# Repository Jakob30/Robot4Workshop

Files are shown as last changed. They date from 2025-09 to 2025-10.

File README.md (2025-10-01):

# Roboterarm – Aufbau und Inbetriebnahme

<p align="center">
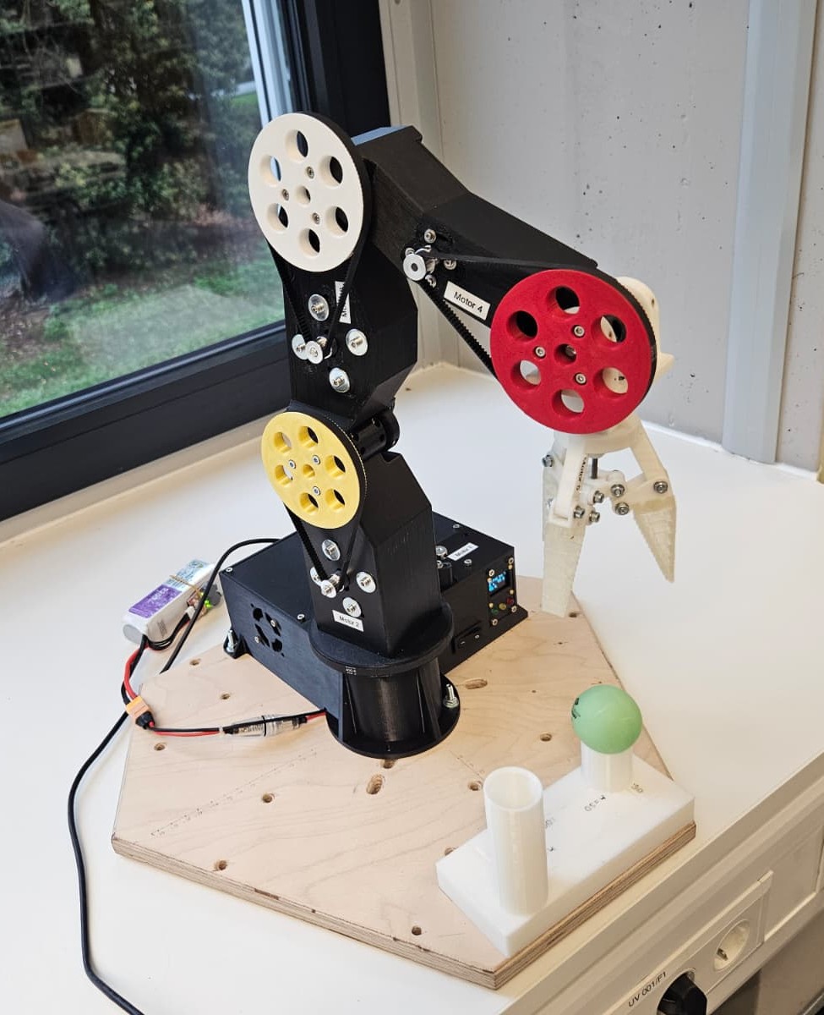
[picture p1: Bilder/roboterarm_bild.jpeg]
Roboterarm
    
</p>    

Dieses Projekt beschreibt den Aufbau und die Inbetriebnahme eines Roboterarms, der mithilfe von 3D-gedruckten Teilen, einer selbstgefertigten Platine und einem STM32F4-Mikrocontroller gesteuert wird.  

---

## 📦 Vorbereitung

1. **3D-Druckteile**  
   - Alle benötigten Teile laut STL-Dateien ausdrucken. Detaillierte Anweisungen befinden sich in dieser [README im Roboterarm Ordner](./Roboterarm/README.md).
   - Qualität und Stabilität der Teile prüfen.  

2. **Bestellung von Bauteilen**  
   - Alle mechanischen und elektronischen Komponenten von der Bestellliste besorgen.  

---

## 🔧 Zusammenbau

Wenn alle 3D-Druckteile und Bauteile vorhanden sind, den Arm gemäß der [**Montageanleitung**](./Roboterarm/Montagehinweise.pdf) zusammenbauen.   

---

## 🖥️ Platine (PCB)

1. **Fertigung**  
   - Platinendaten herunterladen und bei einem Hersteller fertigen lassen. Hinweise zur Platinenfertigung findet man im [Elektronik Ordner](./Elektronik/README.md).

2. **Bestückung**  
   - Bauteile wie Headerpins und Widerstände auf die Platine löten (siehe [README im Elektronik Ordner](./Elektronik/README.md)).  
   - Anschließend können Treiber, Nucleoboard und OLED aufgesteckt werden.

3. **Stromversorgung**  
   - Ein zusätzliches Kabel löten, das den Akku mit der Sicherung, dem Schalter und anschließend mit dem DC/DC-Wandler verbindet.  

---

## ⚙️ STM32F4 – Software

1. **Setup**  
   - [STM32CubeIDE](https://www.st.com/en/development-tools/stm32cubeide.html) installieren.  
   - Projektdateien aus [STM32F4 Ordner](./STM32F4/) importieren.
  
2. **Stromversorgung**  
   - Platine mit Akku oder Netzgerät mit Versorgungsspannung von ca. 15V verbinden.  
   - Schalter umlegen. 
  
3. **Anpassung** 
   - Bewegungen werden im `main.c` programmiert und alle aufzurufenden Funktionen sind in [README](./STM32F4/README.md) beschrieben.  
   - Code per USB auf den Mikrocontroller hochladen.  

---

## 🔍 Kalibrierung mit StallGuard

Vor der ersten Inbetriebnahme ist eine Kalibrierung der StallGuard-Werte notwendig.  
Empfohlen wird die Nutzung von **STM32CubeMonitor**, um Variablen in Echtzeit auszulesen.  

Wichtige Parameter:  
- `STALL_BUFFER_M_X`  
- `LOW_COUNTER_THRESHOLD_M_X`  
- `STALL_MAX_M_X`  

---

## ▶️ Start

1. Vor dem Start den **schwarzen Reset-Knopf** am Nucleo-Board drücken.  
2. Mit dem **blauen Userbutton** das Programm starten.  

---

## 🎥 Beispielvideo

Einen Eindruck, wie der fertige Roboterarm aussehen kann, gibt es hier:  
[➡️ Video ansehen](https://www.dropbox.com/scl/fi/g09jmz12r2tmc5cvw9wto/Robot4Workshop_v4.mp4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)

---

## ✅ Hinweis

- Alle Arbeitsschritte sorgfältig durchführen.  
- Sicherheitsaspekte beim Umgang mit Stromversorgung und Lötarbeiten beachten.

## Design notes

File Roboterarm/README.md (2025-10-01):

# 3D Modelle Roboterarm

Die M3-Einschmelzmuttern sind rot eingefärbt. Verschraubungen vollständig im Modell.

## Creo8 Modell
Alle 3D-Modelle der einzelnen Teile befinden sich im Ordner **`Creo8 Modelle`**.  
Die Baugruppenstruktur ist folgendermaßen verschachtelt:
```
roboterarm_gesamt.asm
│
├─ basis.asm
│ └─ riemenspanner.asm
├─ element1.asm
├─ element2.asm
├─ element3.asm
└─ greifer.asm
  └─ greiferfingereinheit.asm
```

> Hinweis: Alle Dateien liegen unsortiert in einem Ordner.  
> Dadurch kann dieser Ordner direkt als Arbeitsverzeichnis genutzt werden.  
> Die Überbaugruppe **`roboterarm_gesamt.asm`** ruft alle weiteren Dateien automatisch auf.

Die Gesamtbaugruppe ist flexibel und kann per *„Komponente ziehen“* bewegt werden.  
Auch die Greiferbaugruppe ist beweglich.

---

## STEP Modell
Für eine schnelle Ansicht der Gesamtbaugruppe oder für Nutzer ohne Creo8-Zugang kann die Datei  
**`roboterarm_gesamt_asm.stp`** in beliebiger CAD-Software importiert werden.

---

## 3D Druck
Die **`.stl`-Dateien** der 3D-Druckteile befinden sich im Ordner **`STL Dateien`**.  

- Für die **Zahnscheiben** wird höchstens eine **0.4 mm Düse** empfohlen.  
- Die **bionischen Finger** müssen mit flexiblem Filament (z. B. **TPU**) gedruckt werden.

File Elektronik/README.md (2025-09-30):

# Elektronik – PCB_Layout (KiCad)

Diese README beschreibt **alles rund um die Leiterplatte**: warum KiCad, was im Ordner `PCB_Layout/` liegt, wie du die Platine **fertigen lässt**, **Bauteile bestellst**, **bestückst** und **in Betrieb nimmst**.

---

## Warum KiCad?

* **Open‑Source & kostenlos**: Reproduzierbar für alle – ideal für ein Open‑Hardware‑Projekt.
* **Versionierbar**: Textbasierte Projektdateien → gut in Git nutzbar.
* **Ökosystem**: iBOM, DRC/ERC‑Checks, Plugin‑Support.

> Getestet mit **KiCad 8.x**. Ältere Versionen funktionieren u. U. nicht.

---

## Ordnerstruktur

```
Elektronik/
└─ PCB_Layout/
   ├─ PCB_Layout.kicad_pro           # Projektdatei (KiCad 8)
   ├─ PCB_Layout.kicad_sch           # Top‑Schaltplan (inkl. Hierarchie)
   ├─ PCB_Layout.kicad_pcb           # Leiterplattenlayout
   ├─ power.kicad_sch                # Sheet: Versorgung/15 V → 5 V 
   ├─ nucleo_F446RE.kicad_sch        # Sheet: NUCLEO‑F446RE 
   ├─ motor_driver.kicad_sch         # Sheet: TMC2209‑Treiber & Motoranschlüsse
   ├─ display_und_LED.kicad_sch      # Sheet: OLED, LEDs
   ├─ AOM12864A0-1.54WW-ANO/         # **Custom Footprint/Symbol** (OLED 1.54")
   ├─ DM-OLED096-636/                # **Custom Footprint/Symbol** (OLED 0.96")
   ├─ NUCLEO-F446RE/                 # **Custom Footprint/Symbol** (Nucleo STM32)
   ├─ TMC2209_SILENTSTEPSTICK/       # **Custom Footprint/Symbol** (Treiber‑Modul)
   ├─ PCB_Layout----
```

**Hinweis zu den Unterordnern:** `AOM12864…`, `DM‑OLED096‑636`, `NUCLEO‑F446RE`, `TMC2209_SILENTSTEPSTICK` enthalten die **projektspezifischen Bibliotheken** (Symbole/Footprints), die **nicht in KiCads Standard‑Libs** vorhanden sind. Damit bleibt das Projekt **voll reproduzierbar**.

---

## Platinenfertigung – Schritt für Schritt

### 1) Gerber/Bohrdaten erzeugen (KiCad)

1. Projekt öffnen → PCB-Editor.
2. **Datei → Plot**

   * Format: **Gerber**
   * Lagen (typisch 2‑lagig): `F.Cu`, `B.Cu`, `F.SilkS`, `B.SilkS`, `F.Mask`, `B.Mask`, `Edge.Cuts` (ggf. `F.Paste/B.Paste` bei Reflow‑SMD)
   * Allgemeine Optionen → Abwählen **Footprintwerte plotten**
   * **Plotten** → anschl. **Bohrdateien generieren**.

3. **ZIP‑Archiv** aus allen Gerber + Drill → `fabrication/<projekt>_gerbers.zip`.

### 2) Hersteller auswählen & bestellen

Wir haben u. a. bei **Multi‑CB** (Multi Circuit Boards) gefertigt: [https://portal.multi-circuit-boards.eu/](https://portal.multi-circuit-boards.eu/)

**Vorgehen (Beispiel Multi‑CB):**

1. Portal öffnen → Online‑Kalkulator → **Optional: CAD-Datei automatisch auslesen** klicken → **Datei anhängen** und dann `fabrication/<projekt>_gerbers.zip` hochladen.
2. Stückzahl auswählen (z. B. 5–10 Stück) & Lieferzeit.
4. Bestellung abschließen.

> Andere Fertiger funktionieren ebenso, solange sie Standard‑Gerber akzeptieren.

---

## Stückliste (BOM) & Bauteilbestellung

### 1) BOM in KiCad erzeugen

* **Schaltplan‑Editor → Werkzeuge → Stückliste (BoM) erstellen** 
* **Exportieren** als CSV → `outputs/bom.csv`.

### 2) Teile kaufen

* Öffne `bom.csv` → bestelle nach **MPN** (Manufacturer Part Number) bei Distributor deiner Wahl (z. B. Conrad, Mouser, etc.).
* Die restlichen Module (z. B. **TMC2209 Treiber**, **NUCLEO‑F446RE**, **OLED 0.96"**) findest du in [dieser Bestellliste](../Bestellliste.xlsx)

> Tipp: SMD Widerstände/Kondensatoren sind i. d. R. 1206 Hand‑Solder‑freundlich.

---

## Bestückung & Montage

### Reihenfolge (empfohlen)

1. **SMD zuerst**, klein → groß (falls SMD vorhanden). Reflow oder Handlötung.
2. **THT** (Stiftleisten, Buchsenleisten, Schraubklemmen).

>Hinweis: Unten auf dem PCB sieht man, dass die Treiber, MCU und OLED Display direkt auf dem PCB gelötet werden können. Allerdings empfehlen wir, die Buchsenleisten an diesen Stellen zu löten und dann Treiber, MCU, Display darauf zu stecken. Damit lassen sich diese Bauteile problemlos ein-/ausstecken, ohne entlöten zu müssen. 

<p align="center">
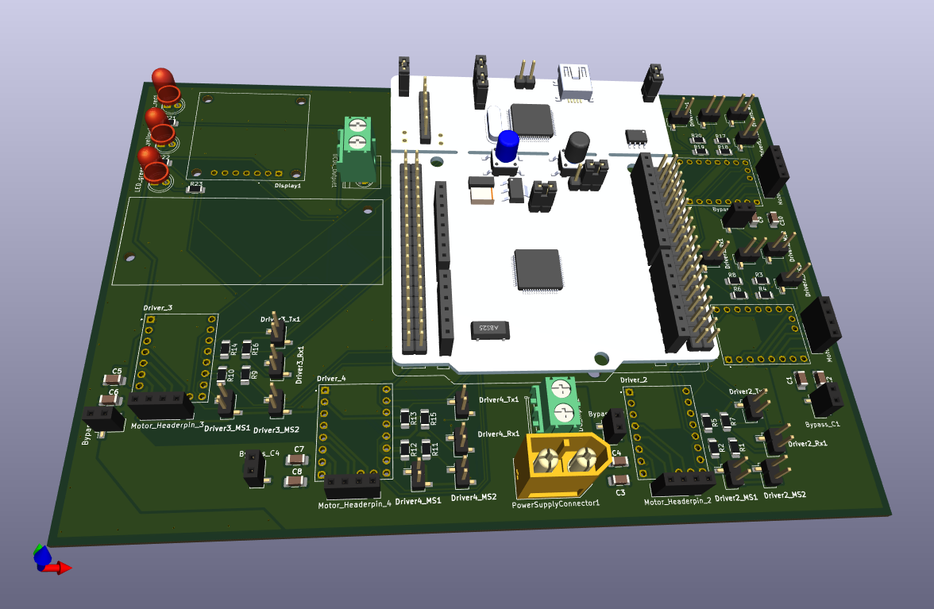
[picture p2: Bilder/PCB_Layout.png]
Roboterarm
    
</p>   

3. **Module** stecken:

   * **TMC2209**‑Module in korrekter **Orientierung** (Silkscreen‑Pfeile/Pin‑1). **Falsches Stecken zerstört den Treiber!**
   * **NUCLEO‑F446RE** Board/Socket einsetzen.
   * **OLED/LEDs** nach Polung.

> **Nie** Module stecken/ziehen, solange die Platine unter Spannung steht.

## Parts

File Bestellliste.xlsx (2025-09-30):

Artikelnummer | Bezeichnung | Anzahl | Kommentar | Stückpreis (inkl. MwSt.) | Gesamtpreis (inkl. MwSt.)
EAN: 4250236821689 | Nema 8 | 2 | Gelenk C (Greifergelenk)/Greiferbetätigung | 19.99 € | 39.98 €
EAN: 4250236818764 | Nema 17-03 | 2 | Gelenk B/Rotation | 12.99 € | 25.98 €
EAN: 4250236815473 | Nema 17-01 | 1 | Gelenk A (höchste Belastung) | 29.99 € | 29.99 €
RBS15481 | GT2 Riemenscheibe Z16 4mm Bohrung für 6mm Zahnriemen | 1 | Riemenscheibe Motor C | 1.05 € | 1.05 €
RBS10278 | GT2 Riemenscheibe Z16 5mm Bohrung für 6mm Zahnriemen | 3 | Riemenscheiben Motor B/A/Rotation | 0.95 € | 2.85 €
EAN:4016138152784 | Silberstahl Welle 6h9 x 500 | 1 | Achsen | 3.99 € | 3.99 €
686-ZZ-MAE | Rillenkugellager 686 (6h6 x 13 x 5) | 6 | Lagerung der Achsen | 0.70 € | 4.20 €
SLSXT22004150 | Akku | 1 | 4S LiPo 2200mAh Akku | 48.40 € | 48.40 €
RX-M3SX4,0 | Gewindeeinsätze für 3D-Druckteile | 1 | Fügen von 3D-Druckteilen | 7.55 € | 7.55 €
RBS13175 | MKS TMC2209 Schrittmotortreiber | 5 | Ansteuerung der Schrittmotoren | 5.65 € | 28.25 €
EAN: 4056534009305 | Pichler Modellbau C5488 LiPo-Summer | 1 | Akku überwachung | 9.95 € | 9.95 €
EAN: 4250236827391 | Joy-it OLED | 1 | Display | 6.99 € | 6.99 €
EAN: 4016139228105 | TRU COMPONENTS Spannungsregler | 1 | 5v Netz | 20.99 € | 20.99 €
61808-2RS-MAE | Kugellager 40x52 | 2 | Basis | 3.44 € | 6.88 €
SLS XT60 Ladekabel | Ladekabel | 1 | Adapter | 6.90 € | 6.90 €
BUL FX0385 | Sicherung | 1 | 10A Schutz | 5.50 € | 5.50 €
EAN: 2050001124593 | Marquardt 1831.3313 Wippschalter | 1 | Hauptschalter | 3.99 € | 3.99 €
EAN: 4053199004027 | Reely RE-6586515 Akku Stecker XT60 | 1 | Anschluss Akku | 1.49 € | 1.49 €
EAN: 2050001435316 | Fischer Elektronik Stiftleiste 1x20 | 2 | Stiftleisten SMD UART Config | 0.76 € | 1.52 €
EAN: 2050001685780 | Fischer Elektronik Buchsenleiste 1x20 | 1 | Buchsenleisten SMD für Bypass-Kondensatoren | 3.29 € | 3.29 €
581-1206YD476MAT2A | SMD Kondensator 47uF 1206 25V | 5 | Bypass Kondensatoren Motorspannung | 0.78 € | 3.92 €
581-12065D106MAT2A | SMD Kondensator 10uF 1206 50V | 5 | Bypass Kondensatoren Motorspannung | 1.31 € | 6.55 €
667-EEU-FS1H331B | THT Elektrolytkondensator Low ESR 330uF 50V | 5 | Bypass Kondensatoren Motorspannung | 0.89 € | 4.46 €
667-EEU-FR1H221 | THT Elektrolytkondensator Low ESR 220uF 50V | 5 | Bypass Kondensatoren Motorspannung | 0.69 € | 3.47 €
EAN: 2050003932752 | TE Connectivity 282836-2 Schraubklemmblock | 1 | Schraubenklemmblock für DC/DC-Converter | 0.64 € | 0.64 €
 | NUCLEO-F446RE | 1 | Mikrocontroller auf Entwicklungsboard | 14.53 € | 14.53 €
 | Leiterplatte | 1 | Verbindung der Komponenten | 35.91 € | 35.91 €
extern besorgt (nicht über die Hochschule)
eBay-Artikelnr.: 285525641166 | Zahnriemen GT2,160 Zähne, Breite 6mm, 3x | 3 | Riemen für bewegliche Segmente | 3.19 € | 9.57 €
eBay-Artikelnr.: 285525641166 | Zahnriemen GT2, 200 Zähne, Breite 6mm, 1x | 1 | Riemen für Basisbewegung | 3.79 € | 3.79 €
 |  |  |  | Gesamtsumme (Stand 22.09.2025): | 342.58 €

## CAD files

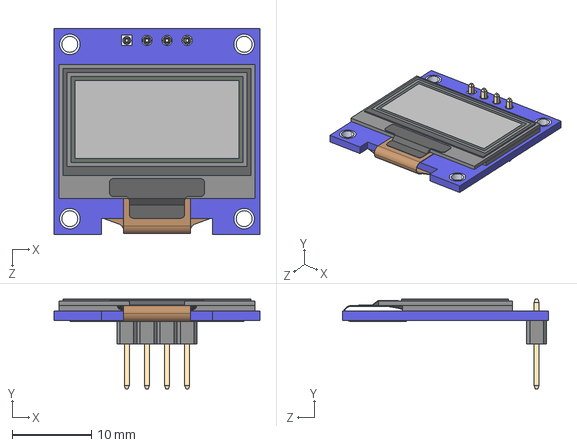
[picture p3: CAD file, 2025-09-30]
Elektronik/PCB_Layout/DM-OLED096-636/DM-OLED096-636.step
26.0 x 11.3 x 26.0 mm
DM-OLED096-636_Module
DM-OLED096-636_Panel

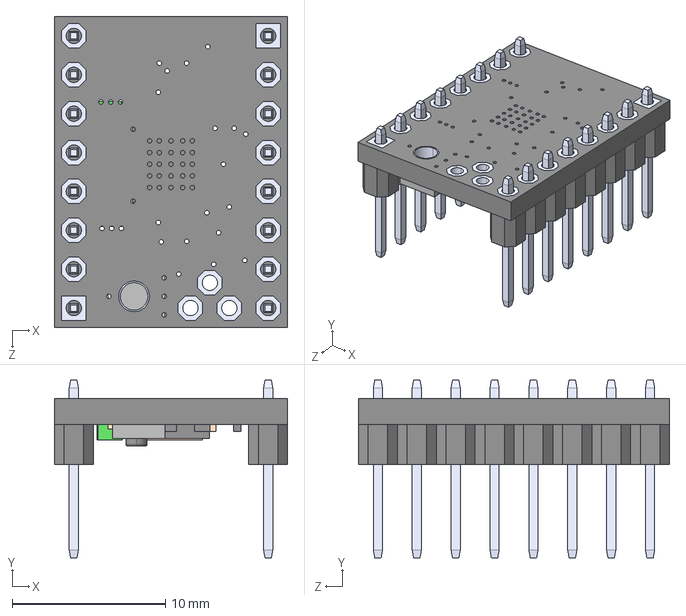
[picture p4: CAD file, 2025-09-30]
Elektronik/PCB_Layout/TMC2209_SILENTSTEPSTICK/TMC2209_SILENTSTEPSTICK.step
15.2 x 11.6 x 20.3 mm

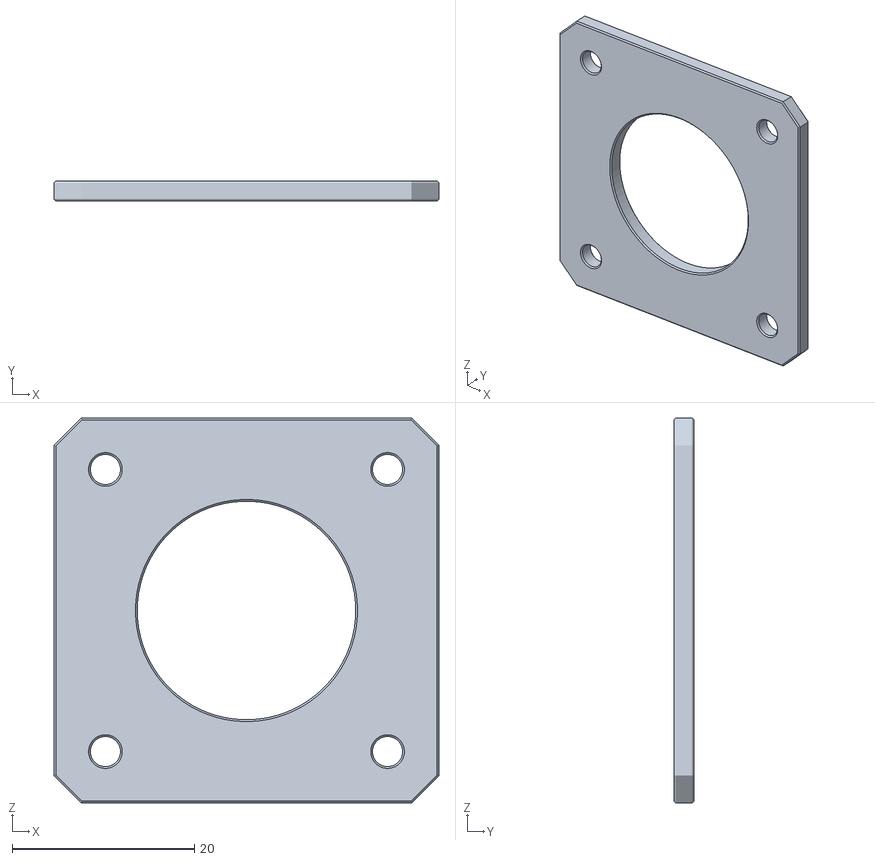
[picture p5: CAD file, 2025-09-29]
Roboterarm/STL Dateien/Basis/distanz_nema17_e1.stl
42.3 x 2.20 x 42.3

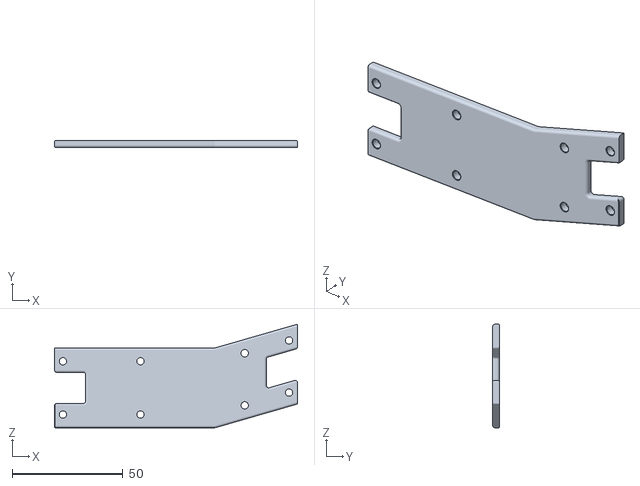
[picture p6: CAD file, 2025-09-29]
Roboterarm/STL Dateien/Element 3/gehaeusedeckel_e3.stl
109.6 x 3.00 x 46.7

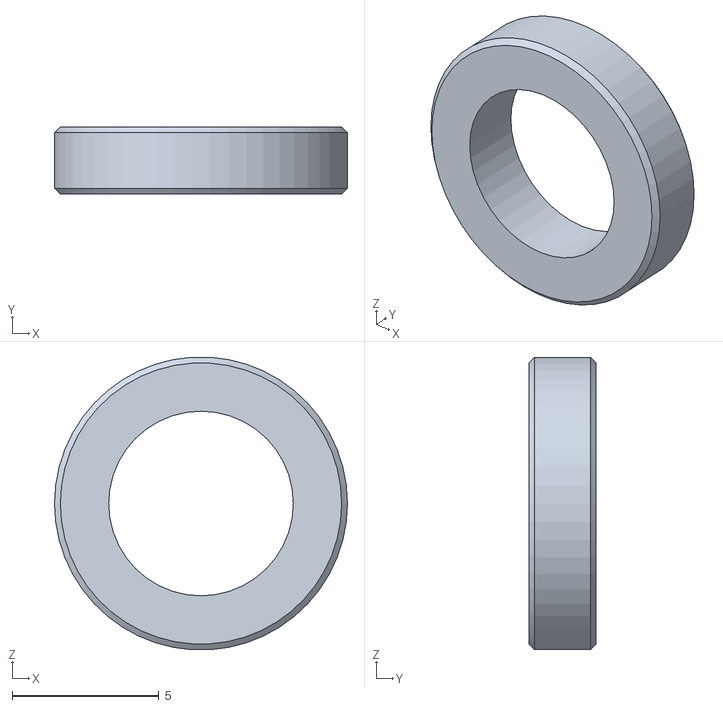
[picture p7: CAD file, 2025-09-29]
Roboterarm/STL Dateien/Greifer/distanzhuelse.stl
10.0 x 2.30 x 9.98

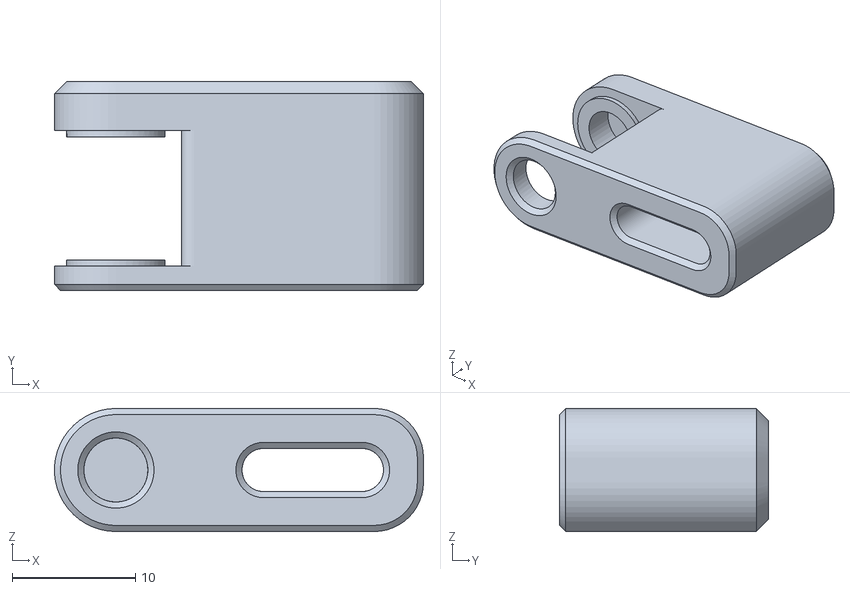
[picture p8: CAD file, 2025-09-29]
Roboterarm/STL Dateien/Basis/gehaeuse_spanner.stl
30.0 x 17.0 x 10.0

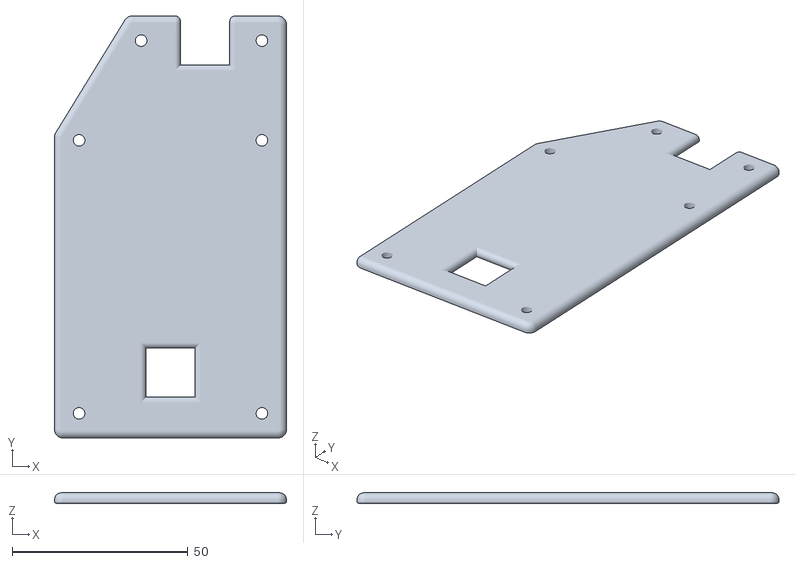
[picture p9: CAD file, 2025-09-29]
Roboterarm/STL Dateien/Element 1/gehaeusedeckel_e1.stl
66.0 x 120.0 x 3.00

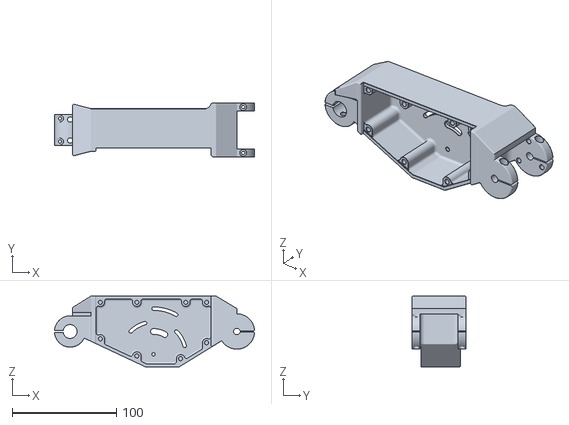
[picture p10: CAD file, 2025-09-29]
Roboterarm/STL Dateien/Element 2/gehaeuse_e2.stl
191.9 x 52.0 x 68.0

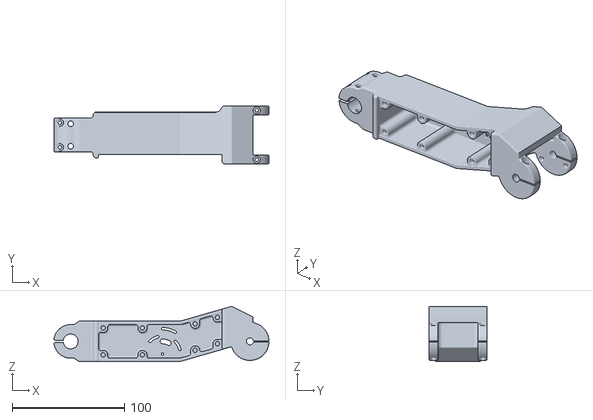
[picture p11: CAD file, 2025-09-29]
Roboterarm/STL Dateien/Element 3/gehaeuse_e3.stl
191.8 x 52.0 x 49.2

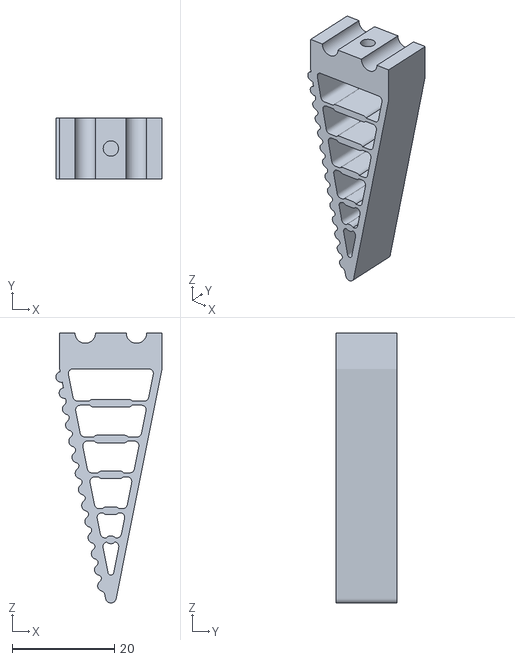
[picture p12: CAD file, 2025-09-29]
Roboterarm/STL Dateien/Greifer/finger_v2_.stl
20.7 x 12.0 x 52.7

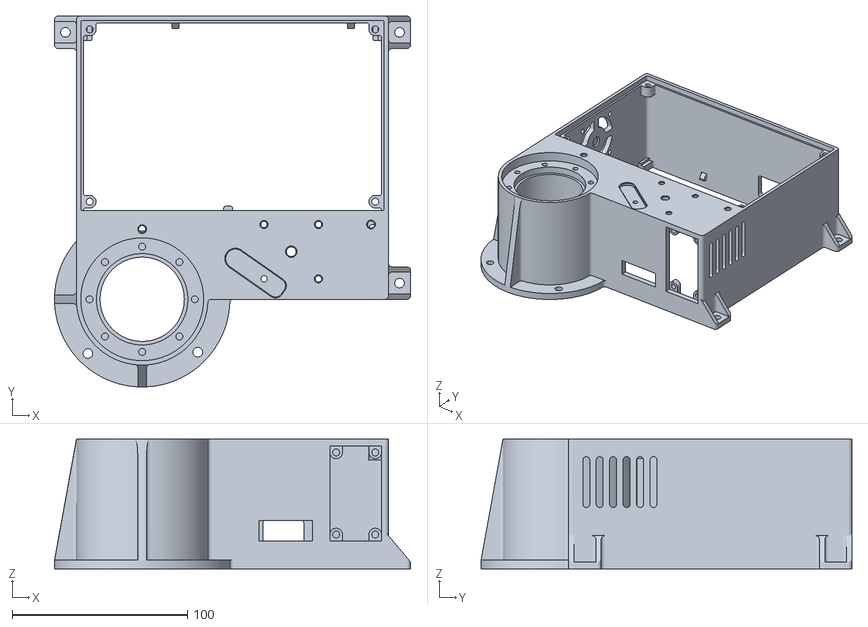
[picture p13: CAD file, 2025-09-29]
Roboterarm/STL Dateien/Basis/grundgehaeuse.stl
203.0 x 211.5 x 74.0

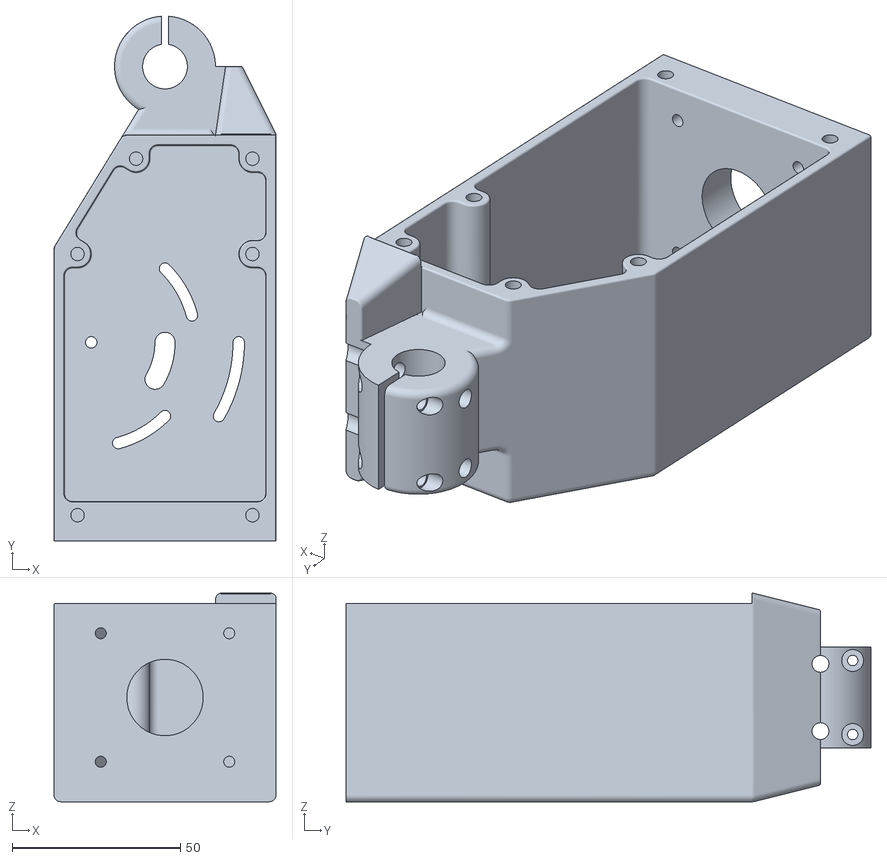
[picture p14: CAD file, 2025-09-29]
Roboterarm/STL Dateien/Element 1/gehaeuse_e1.stl
66.0 x 156.0 x 62.0

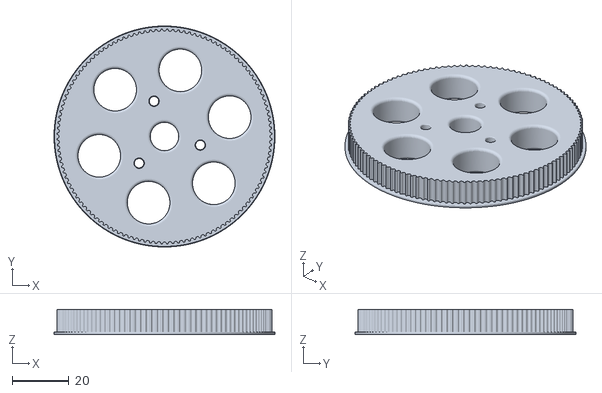
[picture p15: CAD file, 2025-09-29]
Roboterarm/STL Dateien/Element 2/riemenscheibe_120.stl
78.0 x 78.0 x 9.00

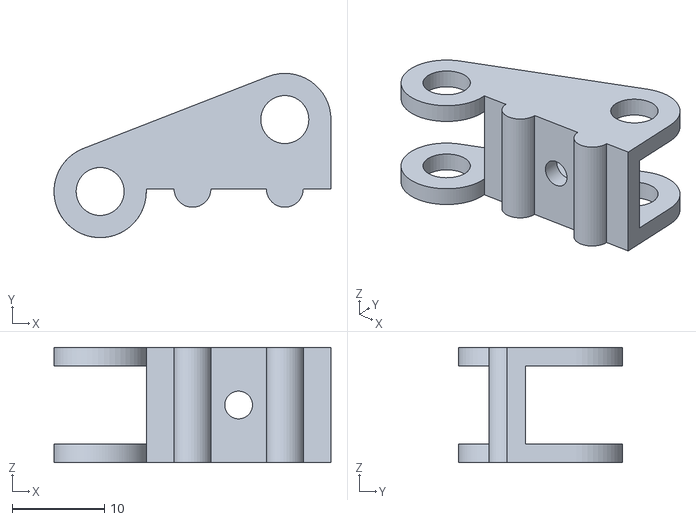
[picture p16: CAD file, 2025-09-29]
Roboterarm/STL Dateien/Greifer/fingeradapter_v2_.stl
30.0 x 17.8 x 12.5

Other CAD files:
Roboterarm/STL Dateien/Element 2/distanz_nema17_e2.stl
Roboterarm/STL Dateien/Basis/rotationsachse.stl
Elektronik/PCB_Layout/AOM12864A0-1.54WW-ANO/AOM12864A0-1.54WW-ANO.step
Roboterarm/STL Dateien/Basis/abdeckung_oben.stl
Roboterarm/STL Dateien/Basis/abdeckung_vorne.stl
Roboterarm/STL Dateien/Basis/lagerspanner.stl
Roboterarm/STL Dateien/Basis/riemenscheibe160.3mf
Roboterarm/STL Dateien/Basis/taster_gehaeuseadapter.stl
Roboterarm/STL Dateien/Element 2/distanz_riemenscheibe_gelenk_a.stl
Roboterarm/STL Dateien/Element 2/gehaeusedeckel_e2.stl
Roboterarm/STL Dateien/Element 3/distanz_nema_0803.stl
Roboterarm/STL Dateien/Greifer/gehaeuse_greifer.stl
Roboterarm/STL Dateien/Greifer/gelenkanbindung.stl
Roboterarm/STL Dateien/Greifer/kupplung.stl
Roboterarm/STL Dateien/Greifer/spindelmutteranbindung.stl
Roboterarm/STL Dateien/Greifer/verbindeglied_.stl

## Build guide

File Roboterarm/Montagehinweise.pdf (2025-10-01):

## Montagehinweise

Der generelle Aufbau des Roboterarms ist in folgende Unterbaugruppen gegliedert:

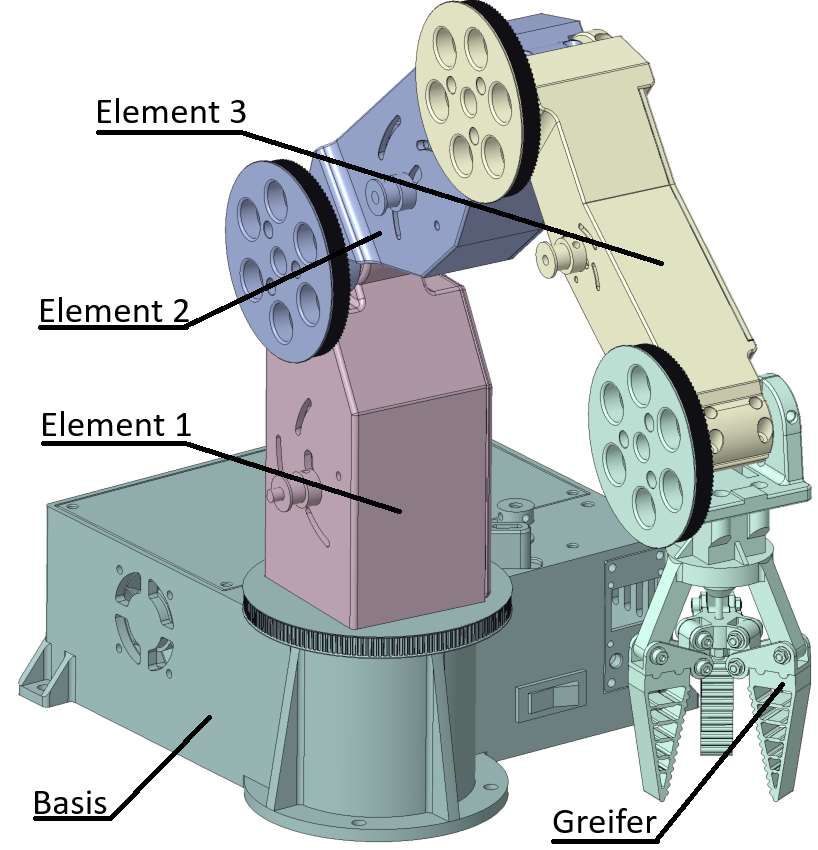
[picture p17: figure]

Sollten Bohrungen durch den 3D-Druck etwas zu klein geraten sein, einfach mit dem passenden Bohrer kurz aufbohren. Alle Schrauben in Langlöchern sollten zur Vergrößerung der Auflagefläche möglichst mit Unterlegscheiben verwendet werden. Die Montage der Einzelbaugruppen ist einfach. Alle Einschmelzmuttern und Schrauben sind im Modell enthalten. Die Einschmelzmuttern sollten alle zuerst eingesetzt werden, bevor mit der Montage begonnen wird. Generell wird empfohlen während der Montage gelegentlich ein Blick ins Modell zu werfen und sich daran zu orientieren. Wenn die einzelnen Baugruppen, bis auf die Gelenkachsen und Abdeckungen montiert sind, kann alles vereint werden.

### Basis

Die Tasteradapter sind eine augesteckte Verlängerung des Reset- und Userbuttons auf dem Nucleo Board und ragen bis durch die obere Abdeckung.
Der Riemenspanner ist mit einer längeren Schraube mit dem Motor verschraubt. Der Spanner kann bei lockerer Schraube in der Aussparung verschoben werden, um die Riemenspannugn anzupassen. In der Abdeckung vorne ist Platz für das kleine Oled Display und drei 5mm Signal LEDs, die per Kabel mit der Platine verbunden sind.

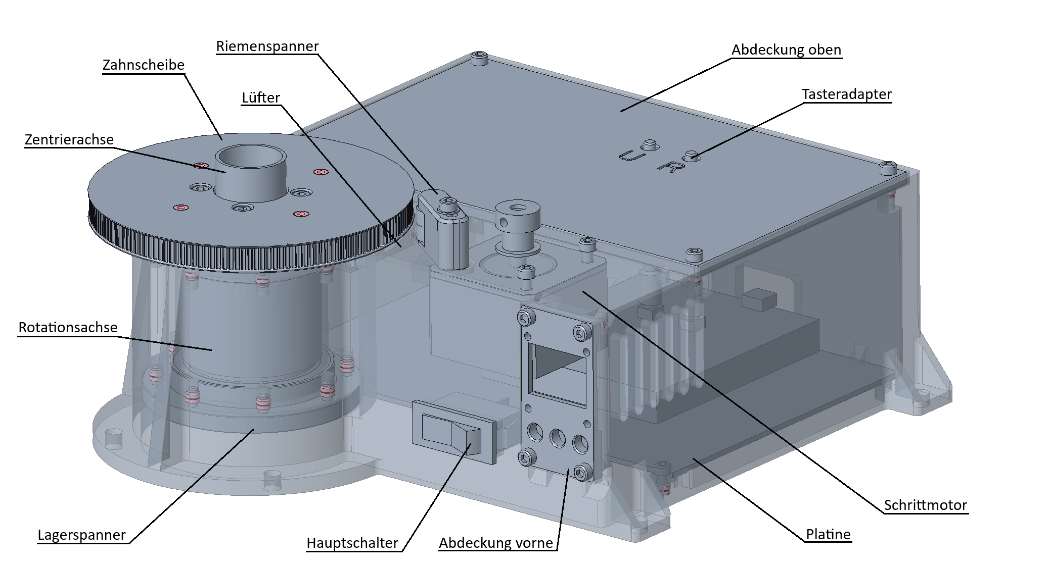
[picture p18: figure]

Die Empfohlene Reihenfolge für die Montage der Lagerung ist folgendermaßen:

1. Einsetzten des unteren Lagers 2. Fixieren mit dem unteren Lagerspanner 3. Einsetzen der Zentrierachse in die Rotationsachse 4. Einsetzten des oberen Lagers auf die Rotationsachse 5. Einsetzen der Rotationsachse, samt Lager und Zentrierung von oben ins Gehäuse 6. Fixieren mit dem oberen Lagerspanner 7. Einschrauben der Anschlagschraube 8. Aufsetzen der Zahnscheibe und verschrauben

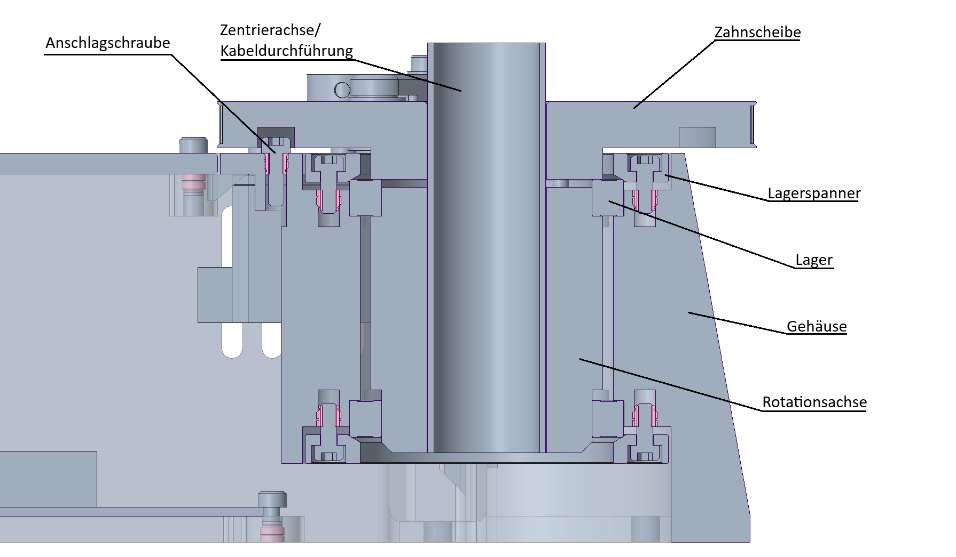
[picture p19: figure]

### Element 1 (E1)

Für die drei Armelemente wird empfohlen die Abdeckungen vorerst demontiert zu lassen.
Bei Element 1 kann außerdem der Schrittmotor erst nach der Montage auf die Basis festgeschraubt werden. Ansonsten kommt man nicht mehr an die Schrauben an der Unterseite. Die Kugellager werden mit den beiden Schrauben ganz oben im folgenden Bild geklemmt.

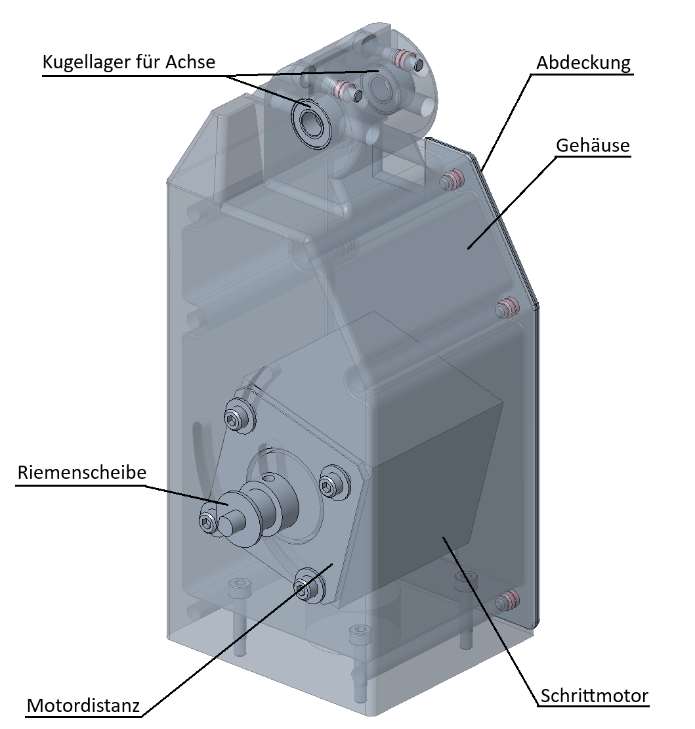
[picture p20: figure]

### Element 2 (E2)

Die Montage von Element 2 ist ähnlich wie die von Element 1. Nur kommt noch die Montage der Distanz und Zahnscheibe hinzu. Die Anbringung der Zahnscheibe sollte erst nach dem vereinen von Element 1 und Element 2 durchgeführt werden.

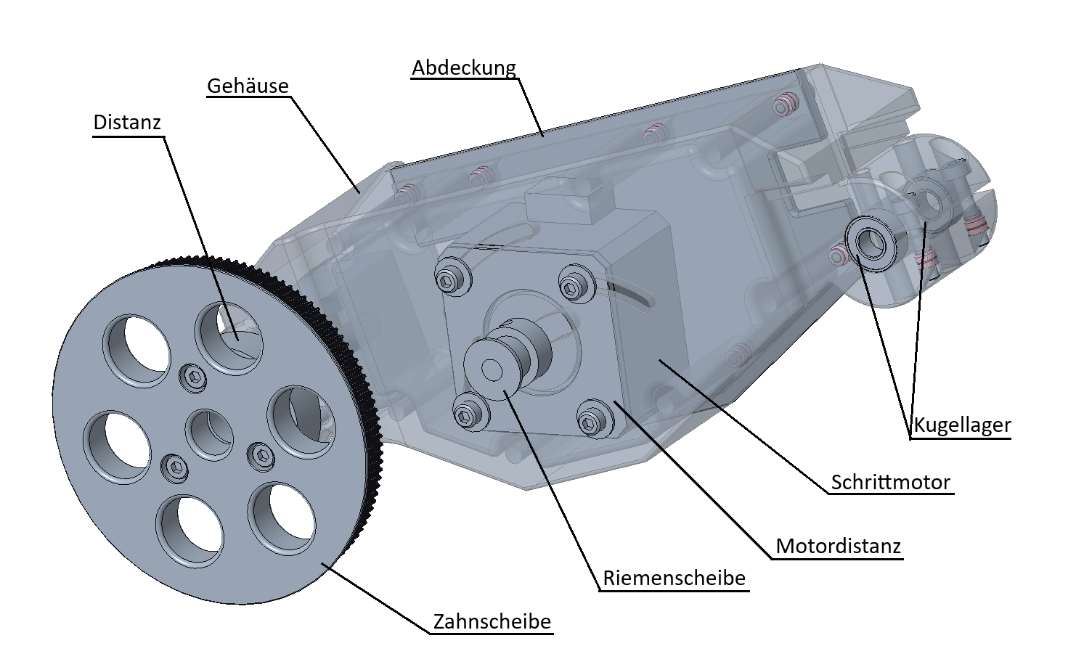
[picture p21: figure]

### Element 3 (E3)

Die Montage von Element 3 unterscheidet sich nur durch das Fehlen der Distanz unter der Zahnscheibe

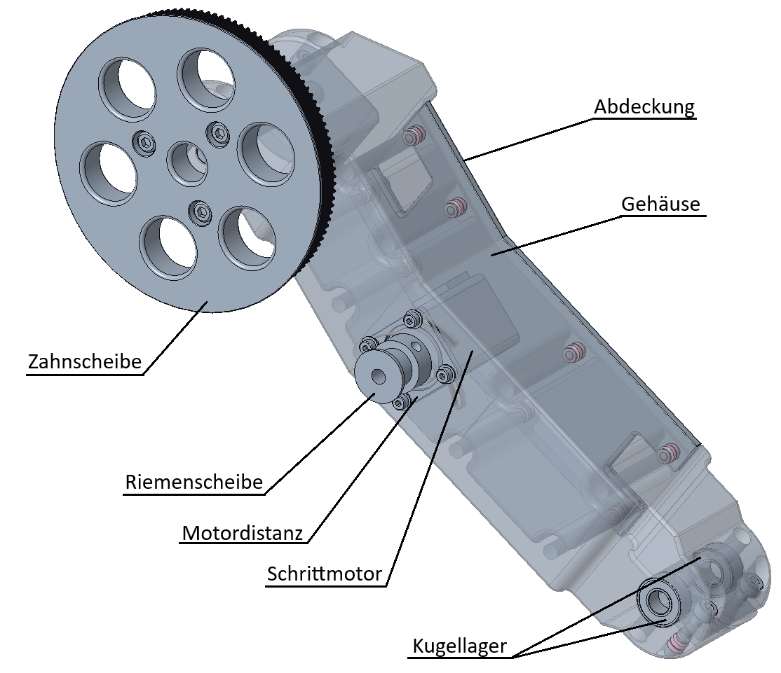
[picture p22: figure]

### Greifer:

Die Riffelung der Greifer soll nach innen zeigen.
Die Gewindestange muss in die Einschmelzmutter der Kupplung mit Gewindesicherung eingeklebt werden.
Um Einklemmen der Motorleitungen im Gelenk zu verhindern, können die Kabel durch die Kabeldurchführungen außerhalb verlegt werden.
Es befinden sich sechs Hülsen im Greifermechanismus in den Gelenken an Verbindeglied und Fingeradapter, die von außen nicht sichtbar sind, aber wichtig für die Leichtgängigkeit sind. Auf diese sollte geachtet werden.

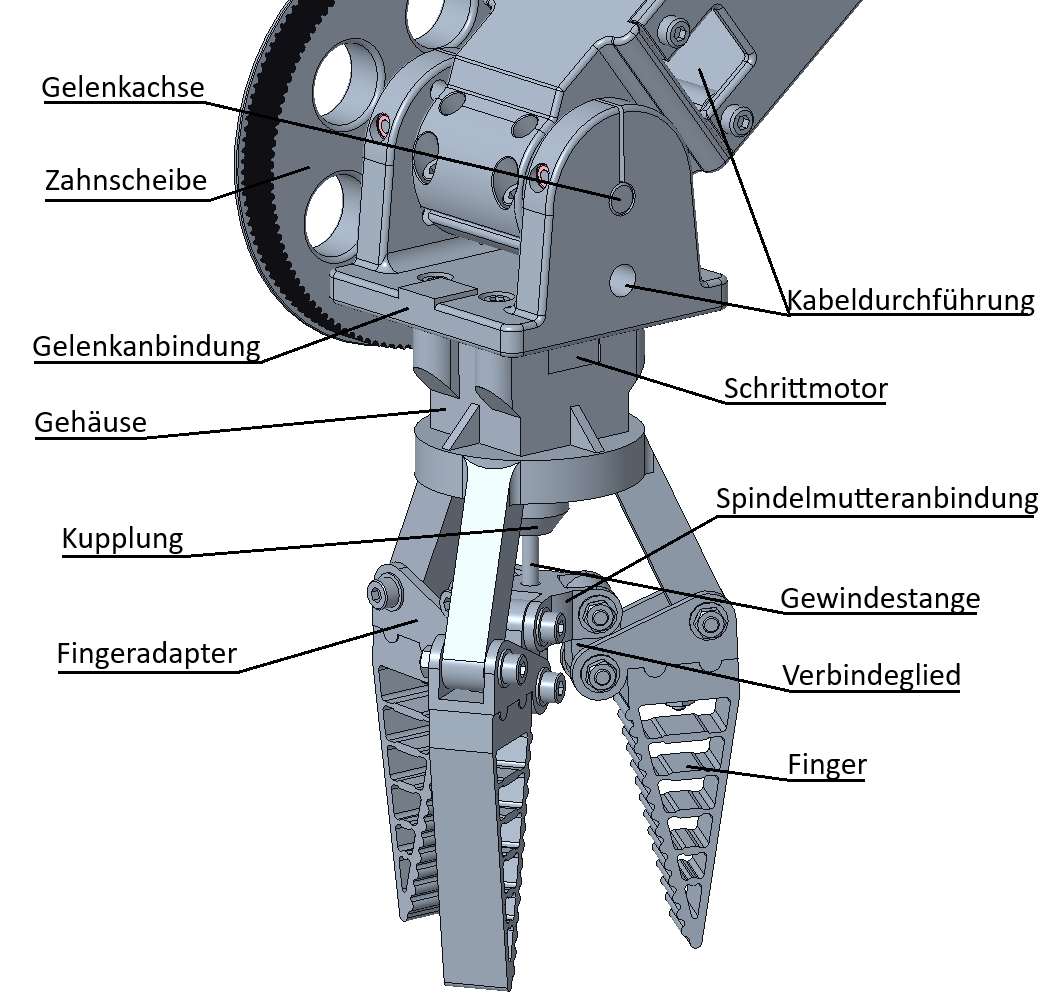
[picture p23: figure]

### Zusammenfügen

Beim Schrauben von Element 1 auf die Basis muss darauf geachtet werden, dass die Ausrichtung der Anschlagnut auf der richtigen Seite ist. Sonst hat der Arm eine eingeschränkte Drehfreiheit. Für eine volle Drehung ist Element 1 wir in folgender Abbildung mit den vier Befestigungsschrauben auf die Zahnscheibe der Basis zu schrauben. Danach kann auch der Schrittmotor eingesetzt werden.

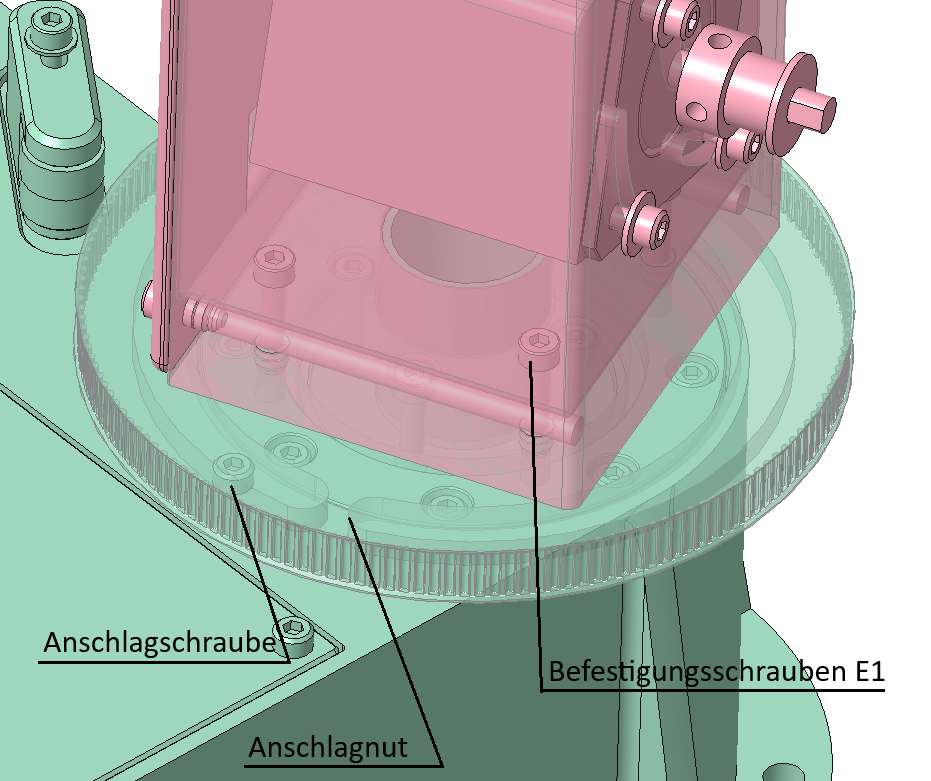
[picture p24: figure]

Die weiteren Baugruppen werden an den Gelenken A (E1-E2), B (E2-E3) und C (E3-Greifer) folgendermaßen zusammengesetzt : Beispiel zu Gelenk A

### 1. Kugellager von E1 fluchtend zueinander klemmen 2. Zwei Baugruppen aneinander halten 3. Achse durchstecken 4. Klemmschrauben E2 anziehen 5. Zahnscheibe E2 ans Gehäuse schrauben

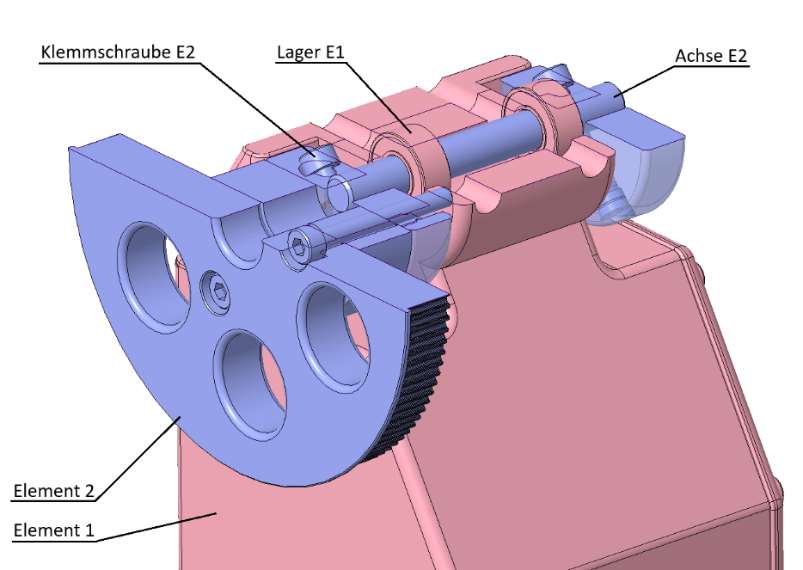
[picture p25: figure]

Nach der Montage aller Teile kann die Riemenspannung eingestellt werden. Dazu einfach die Schrauben an den Motoren lösen, den Riemen spannen und anschließend wieder festschrauben

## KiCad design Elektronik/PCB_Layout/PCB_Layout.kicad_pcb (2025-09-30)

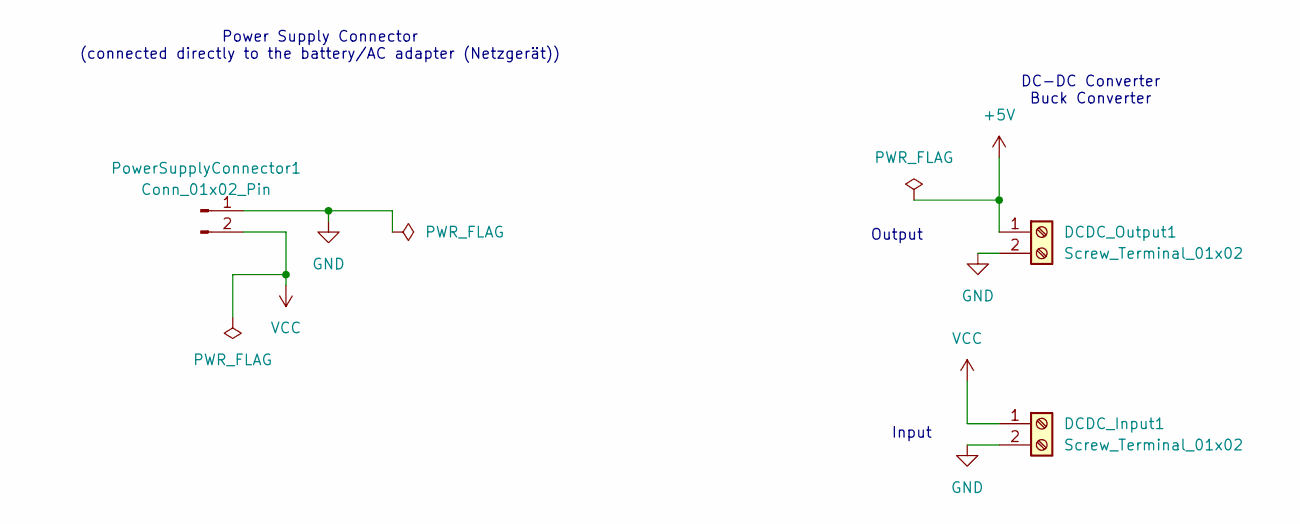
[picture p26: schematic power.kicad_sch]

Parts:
DCDC_Input1: Screw_Terminal_01x02; TerminalBlock_Phoenix_PT-1,5-2-5.0-H_1x02_P5.00mm_Horizontal
DCDC_Output1: Screw_Terminal_01x02; DC_DC_Converter_with_Screw_Terminal
PowerSupplyConnector1: Conn_01x02_Pin; AMASS_XT60-M_1x02_P7.20mm_Vertical

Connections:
+5V: DCDC_Output1.1; also elsewhere on the board
GND: DCDC_Input1.2, DCDC_Output1.2, PowerSupplyConnector1.1; also elsewhere on the board
VCC: DCDC_Input1.1, PowerSupplyConnector1.2; also elsewhere on the board

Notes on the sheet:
Input
Power Supply Connector (connected directly to the battery/AC adapter (Netzgerät))
Output
DC-DC Converter Buck Converter

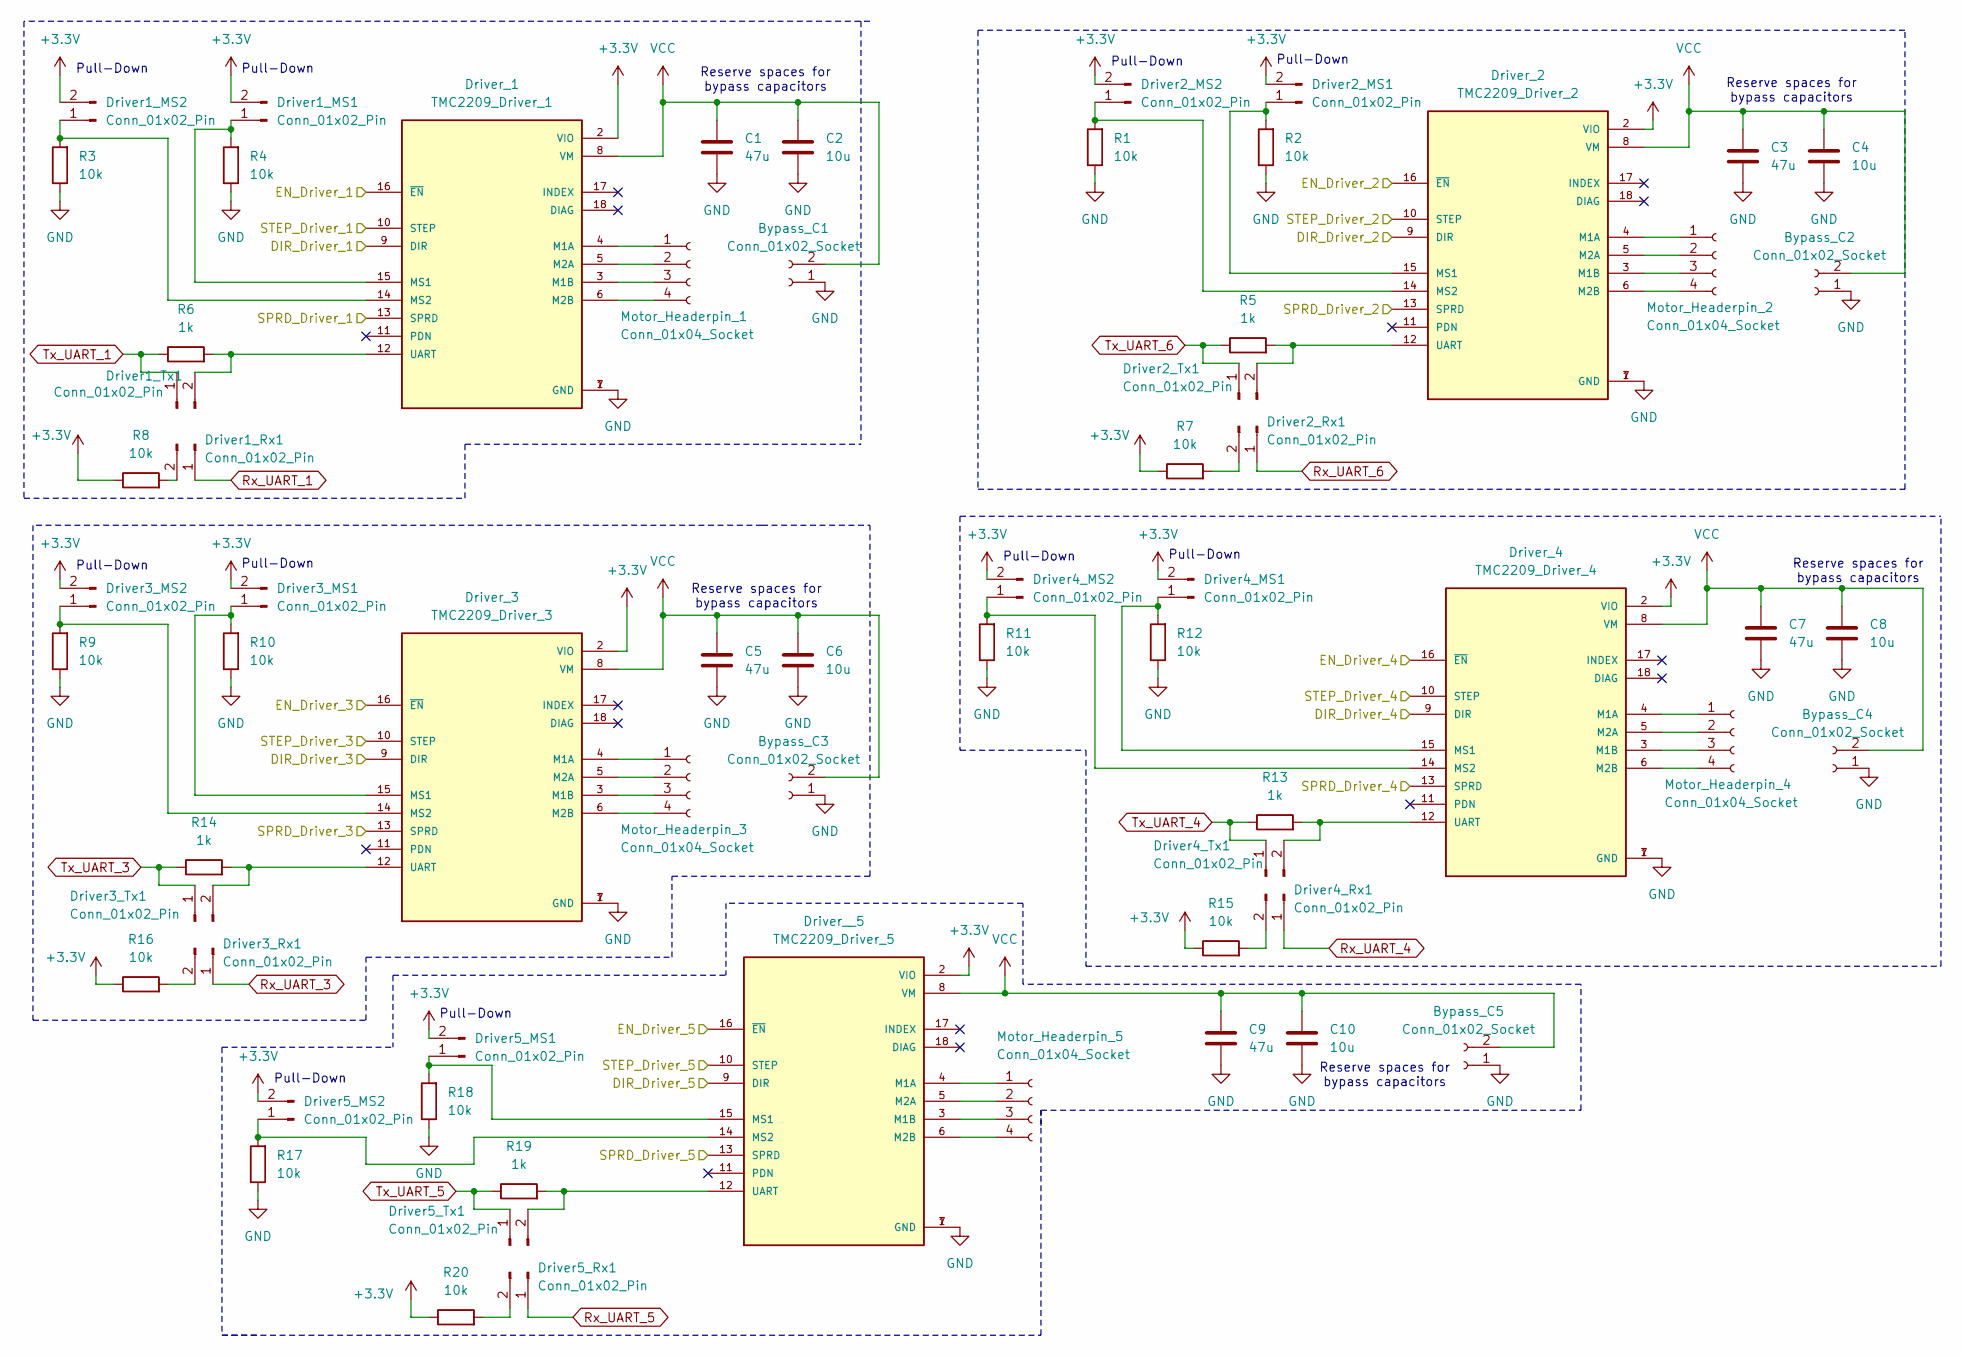
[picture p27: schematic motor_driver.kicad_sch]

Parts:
Bypass_C1, Bypass_C2, Bypass_C3, Bypass_C4, Bypass_C5: Conn_01x02_Socket; PinSocket_1x02_P2.54mm_Vertical_SMD_Pin1Left
C1, C3, C5, C7, C9: 47u; C_1206_3216Metric_Pad1.33x1.80mm_HandSolder
C2, C4, C6, C8, C10: 10u; C_1206_3216Metric_Pad1.33x1.80mm_HandSolder
Driver1_MS1, Driver1_MS2, Driver1_Rx1, Driver1_Tx1, Driver2_MS1, Driver2_MS2, Driver2_Rx1, Driver2_Tx1, Driver3_MS1, Driver3_MS2, Driver3_Rx1, Driver3_Tx1, Driver4_MS1, Driver4_MS2, Driver4_Rx1, Driver4_Tx1, Driver5_MS1, Driver5_MS2, Driver5_Rx1, Driver5_Tx1: Conn_01x02_Pin; PinHeader_1x02_P2.54mm_Vertical_SMD_Pin1Left
Driver_1: TMC2209_Driver_1; MODULE_TMC2209_SILENTSTEPSTICK; PARTREV 1.20
Driver_2: TMC2209_Driver_2; MODULE_TMC2209_SILENTSTEPSTICK; PARTREV 1.20
Driver_3: TMC2209_Driver_3; MODULE_TMC2209_SILENTSTEPSTICK; PARTREV 1.20
Driver_4: TMC2209_Driver_4; MODULE_TMC2209_SILENTSTEPSTICK; PARTREV 1.20
Driver__5: TMC2209_Driver_5; MODULE_TMC2209_SILENTSTEPSTICK; PARTREV 1.20
Motor_Headerpin_1, Motor_Headerpin_2, Motor_Headerpin_3, Motor_Headerpin_4, Motor_Headerpin_5: Conn_01x04_Socket; PinSocket_1x04_P2.54mm_Vertical
R1, R2, R3, R4, R7, R8, R9, R10, R11, R12, R15, R16, R17, R18, R20: 10k; R_1206_3216Metric_Pad1.30x1.75mm_HandSolder
R5, R6, R13, R14, R19: 1k; R_1206_3216Metric_Pad1.30x1.75mm_HandSolder

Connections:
+3.3V: Driver1_MS1.2, Driver1_MS2.2, Driver2_MS1.2, Driver2_MS2.2, Driver3_MS1.2, Driver3_MS2.2, Driver4_MS1.2, Driver4_MS2.2, Driver5_MS1.2, Driver5_MS2.2, Driver_1.2 (VIO), Driver_2.2 (VIO), Driver_3.2 (VIO), Driver_4.2 (VIO), Driver__5.2 (VIO), R7.1, R8.1, R15.1, R16.1, R20.1; also elsewhere on the board
/motor_driver/DIR_Driver_1: Driver_1.9 (DIR); also elsewhere on the board
/motor_driver/DIR_Driver_2: Driver_2.9 (DIR); also elsewhere on the board
/motor_driver/DIR_Driver_3: Driver_3.9 (DIR); also elsewhere on the board
/motor_driver/DIR_Driver_4: Driver_4.9 (DIR); also elsewhere on the board
/motor_driver/DIR_Driver_5: Driver__5.9 (DIR); also elsewhere on the board
/motor_driver/EN_Driver_1: Driver_1.16 (~EN); also elsewhere on the board
/motor_driver/EN_Driver_2: Driver_2.16 (~EN); also elsewhere on the board
/motor_driver/EN_Driver_3: Driver_3.16 (~EN); also elsewhere on the board
/motor_driver/EN_Driver_4: Driver_4.16 (~EN); also elsewhere on the board
/motor_driver/EN_Driver_5: Driver__5.16 (~EN); also elsewhere on the board
/motor_driver/SPRD_Driver_1: Driver_1.13 (SPRD); also elsewhere on the board
/motor_driver/SPRD_Driver_2: Driver_2.13 (SPRD); also elsewhere on the board
/motor_driver/SPRD_Driver_3: Driver_3.13 (SPRD); also elsewhere on the board
/motor_driver/SPRD_Driver_4: Driver_4.13 (SPRD); also elsewhere on the board
/motor_driver/SPRD_Driver_5: Driver__5.13 (SPRD); also elsewhere on the board
/motor_driver/STEP_Driver_1: Driver_1.10 (STEP); also elsewhere on the board
/motor_driver/STEP_Driver_2: Driver_2.10 (STEP); also elsewhere on the board
/motor_driver/STEP_Driver_3: Driver_3.10 (STEP); also elsewhere on the board
/motor_driver/STEP_Driver_4: Driver_4.10 (STEP); also elsewhere on the board
/motor_driver/STEP_Driver_5: Driver__5.10 (STEP); also elsewhere on the board
GND: Bypass_C1.1, Bypass_C2.1, Bypass_C3.1, Bypass_C4.1, Bypass_C5.1, C1.2, C2.2, C3.2, C4.2, C5.2, C6.2, C7.2, C8.2, C9.2, C10.2, Driver_1.1 (GND), Driver_1.7 (GND), Driver_2.1 (GND), Driver_2.7 (GND), Driver_3.1 (GND), Driver_3.7 (GND), Driver_4.1 (GND), Driver_4.7 (GND), Driver__5.1 (GND), Driver__5.7 (GND), R1.1, R2.1, R3.1, R4.1, R9.1, R10.1, R11.1, R12.1, R17.1, R18.1; also elsewhere on the board
unnamed: Driver1_MS1.1, Driver_1.15 (MS1), R4.2
unnamed: Driver1_MS2.1, Driver_1.14 (MS2), R3.2
unnamed: Driver1_Rx1.2, R8.2
unnamed: Driver1_Tx1.2, Driver_1.12 (UART), R6.2
unnamed: Driver2_MS1.1, Driver_2.15 (MS1), R2.2
unnamed: Driver2_MS2.1, Driver_2.14 (MS2), R1.2
unnamed: Driver2_Rx1.2, R7.2
unnamed: Driver2_Tx1.2, Driver_2.12 (UART), R5.2
unnamed: Driver3_MS1.1, Driver_3.15 (MS1), R10.2
unnamed: Driver3_MS2.1, Driver_3.14 (MS2), R9.2
unnamed: Driver3_Rx1.2, R16.2
unnamed: Driver3_Tx1.2, Driver_3.12 (UART), R14.2
unnamed: Driver4_MS1.1, Driver_4.15 (MS1), R12.2
unnamed: Driver4_MS2.1, Driver_4.14 (MS2), R11.2
unnamed: Driver4_Rx1.2, R15.2
unnamed: Driver4_Tx1.2, Driver_4.12 (UART), R13.2
unnamed: Driver5_MS1.1, Driver__5.15 (MS1), R18.2
unnamed: Driver5_MS2.1, Driver__5.14 (MS2), R17.2
unnamed: Driver5_Rx1.2, R20.2
unnamed: Driver5_Tx1.2, Driver__5.12 (UART), R19.2
unnamed: Driver_1.4 (M1A), Motor_Headerpin_1.1
unnamed: Driver_1.3 (M1B), Motor_Headerpin_1.3
unnamed: Driver_1.5 (M2A), Motor_Headerpin_1.2
unnamed: Driver_1.6 (M2B), Motor_Headerpin_1.4
unnamed: Driver_2.4 (M1A), Motor_Headerpin_2.1
unnamed: Driver_2.3 (M1B), Motor_Headerpin_2.3
unnamed: Driver_2.5 (M2A), Motor_Headerpin_2.2
unnamed: Driver_2.6 (M2B), Motor_Headerpin_2.4
unnamed: Driver_3.4 (M1A), Motor_Headerpin_3.1
unnamed: Driver_3.3 (M1B), Motor_Headerpin_3.3
unnamed: Driver_3.5 (M2A), Motor_Headerpin_3.2
unnamed: Driver_3.6 (M2B), Motor_Headerpin_3.4
unnamed: Driver_4.4 (M1A), Motor_Headerpin_4.1
unnamed: Driver_4.3 (M1B), Motor_Headerpin_4.3
unnamed: Driver_4.5 (M2A), Motor_Headerpin_4.2
unnamed: Driver_4.6 (M2B), Motor_Headerpin_4.4
unnamed: Driver__5.4 (M1A), Motor_Headerpin_5.1
unnamed: Driver__5.3 (M1B), Motor_Headerpin_5.3
unnamed: Driver__5.5 (M2A), Motor_Headerpin_5.2
unnamed: Driver__5.6 (M2B), Motor_Headerpin_5.4
Rx_UART_1: Driver1_Rx1.1; also elsewhere on the board
Rx_UART_3: Driver3_Rx1.1; also elsewhere on the board
Rx_UART_4: Driver4_Rx1.1; also elsewhere on the board
Rx_UART_5: Driver5_Rx1.1; also elsewhere on the board
Rx_UART_6: Driver2_Rx1.1; also elsewhere on the board
Tx_UART_1: Driver1_Tx1.1, R6.1; also elsewhere on the board
Tx_UART_3: Driver3_Tx1.1, R14.1; also elsewhere on the board
Tx_UART_4: Driver4_Tx1.1, R13.1; also elsewhere on the board
Tx_UART_5: Driver5_Tx1.1, R19.1; also elsewhere on the board
Tx_UART_6: Driver2_Tx1.1, R5.1; also elsewhere on the board
VCC: Bypass_C1.2, Bypass_C2.2, Bypass_C3.2, Bypass_C4.2, Bypass_C5.2, C1.1, C2.1, C3.1, C4.1, C5.1, C6.1, C7.1, C8.1, C9.1, C10.1, Driver_1.8 (VM), Driver_2.8 (VM), Driver_3.8 (VM), Driver_4.8 (VM), Driver__5.8 (VM); also elsewhere on the board

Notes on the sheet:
Reserve spaces for bypass capacitors
Pull-Down
Reserve spaces for bypass capacitors

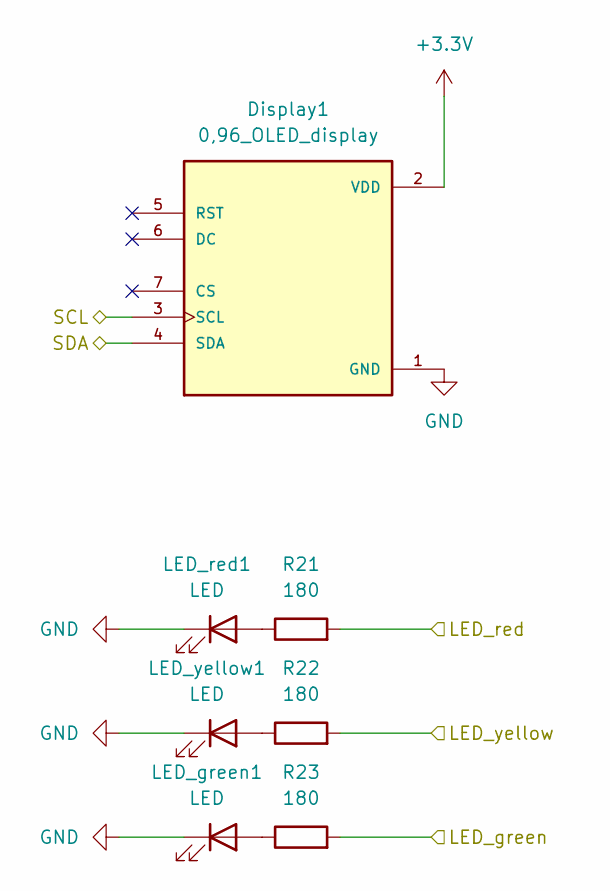
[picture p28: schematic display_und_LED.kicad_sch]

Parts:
Display1: 0,96_OLED_display; 0,96_OLED_Display; PARTREV O
LED_green1: LED; LED_D5.0mm
LED_red1: LED; LED_D5.0mm
LED_yellow1: LED; LED_D5.0mm
R21, R22, R23: 180; R_1206_3216Metric_Pad1.30x1.75mm_HandSolder

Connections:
+3.3V: Display1.2 (VDD); also elsewhere on the board
/display_und_LED/LED_green: R23.2; also elsewhere on the board
/display_und_LED/LED_red: R21.2; also elsewhere on the board
/display_und_LED/LED_yellow: R22.2; also elsewhere on the board
/display_und_LED/SCL: Display1.3 (SCL); also elsewhere on the board
/display_und_LED/SDA: Display1.4 (SDA); also elsewhere on the board
GND: Display1.1 (GND), LED_green1.1 (K), LED_red1.1 (K), LED_yellow1.1 (K); also elsewhere on the board
unnamed: LED_green1.2 (A), R23.1
unnamed: LED_red1.2 (A), R21.1
unnamed: LED_yellow1.2 (A), R22.1

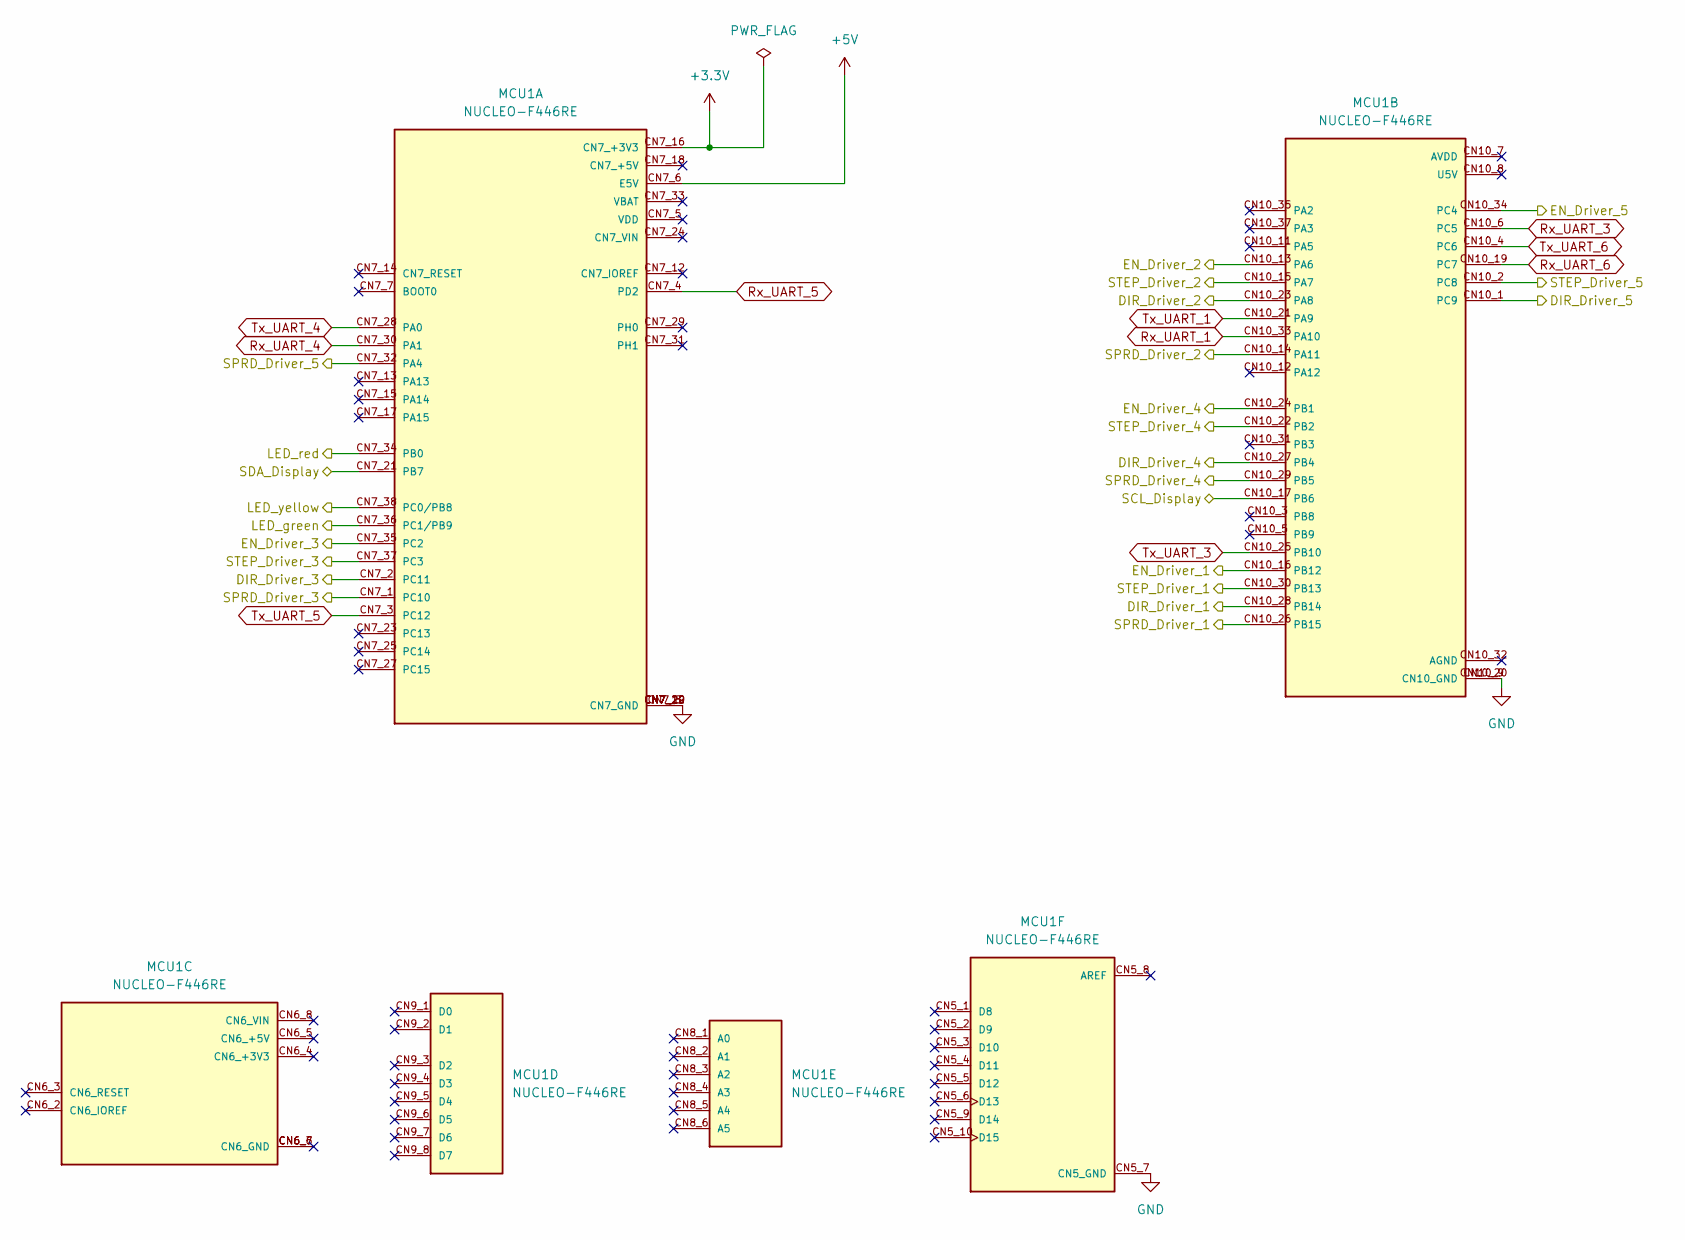
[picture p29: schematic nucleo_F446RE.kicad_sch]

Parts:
MCU1: NUCLEO-F446RE; MODULE_NUCLEO-F446RE; PARTREV 13

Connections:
+3.3V: MCU1.CN7_16 (CN7_+3V3); also elsewhere on the board
+5V: MCU1.CN7_6 (E5V); also elsewhere on the board
/display_und_LED/LED_green: MCU1.CN7_36 (PC1/PB9); also elsewhere on the board
/display_und_LED/LED_red: MCU1.CN7_34 (PB0); also elsewhere on the board
/display_und_LED/LED_yellow: MCU1.CN7_38 (PC0/PB8); also elsewhere on the board
/display_und_LED/SCL: MCU1.CN10_17 (PB6); also elsewhere on the board
/display_und_LED/SDA: MCU1.CN7_21 (PB7); also elsewhere on the board
/motor_driver/DIR_Driver_1: MCU1.CN10_28 (PB14); also elsewhere on the board
/motor_driver/DIR_Driver_2: MCU1.CN10_23 (PA8); also elsewhere on the board
/motor_driver/DIR_Driver_3: MCU1.CN7_2 (PC11); also elsewhere on the board
/motor_driver/DIR_Driver_4: MCU1.CN10_27 (PB4); also elsewhere on the board
/motor_driver/DIR_Driver_5: MCU1.CN10_1 (PC9); also elsewhere on the board
/motor_driver/EN_Driver_1: MCU1.CN10_16 (PB12); also elsewhere on the board
/motor_driver/EN_Driver_2: MCU1.CN10_13 (PA6); also elsewhere on the board
/motor_driver/EN_Driver_3: MCU1.CN7_35 (PC2); also elsewhere on the board
/motor_driver/EN_Driver_4: MCU1.CN10_24 (PB1); also elsewhere on the board
/motor_driver/EN_Driver_5: MCU1.CN10_34 (PC4); also elsewhere on the board
/motor_driver/SPRD_Driver_1: MCU1.CN10_26 (PB15); also elsewhere on the board
/motor_driver/SPRD_Driver_2: MCU1.CN10_14 (PA11); also elsewhere on the board
/motor_driver/SPRD_Driver_3: MCU1.CN7_1 (PC10); also elsewhere on the board
/motor_driver/SPRD_Driver_4: MCU1.CN10_29 (PB5); also elsewhere on the board
/motor_driver/SPRD_Driver_5: MCU1.CN7_32 (PA4); also elsewhere on the board
/motor_driver/STEP_Driver_1: MCU1.CN10_30 (PB13); also elsewhere on the board
/motor_driver/STEP_Driver_2: MCU1.CN10_15 (PA7); also elsewhere on the board
/motor_driver/STEP_Driver_3: MCU1.CN7_37 (PC3); also elsewhere on the board
/motor_driver/STEP_Driver_4: MCU1.CN10_22 (PB2); also elsewhere on the board
/motor_driver/STEP_Driver_5: MCU1.CN10_2 (PC8); also elsewhere on the board
GND: MCU1.CN5_7 (CN5_GND), MCU1.CN7_8 (CN7_GND), MCU1.CN7_19 (CN7_GND), MCU1.CN7_20 (CN7_GND), MCU1.CN7_22 (CN7_GND), MCU1.CN10_9 (CN10_GND), MCU1.CN10_20 (CN10_GND); also elsewhere on the board
Rx_UART_1: MCU1.CN10_33 (PA10); also elsewhere on the board
Rx_UART_3: MCU1.CN10_6 (PC5); also elsewhere on the board
Rx_UART_4: MCU1.CN7_30 (PA1); also elsewhere on the board
Rx_UART_5: MCU1.CN7_4 (PD2); also elsewhere on the board
Rx_UART_6: MCU1.CN10_19 (PC7); also elsewhere on the board
Tx_UART_1: MCU1.CN10_21 (PA9); also elsewhere on the board
Tx_UART_3: MCU1.CN10_25 (PB10); also elsewhere on the board
Tx_UART_4: MCU1.CN7_28 (PA0); also elsewhere on the board
Tx_UART_5: MCU1.CN7_3 (PC12); also elsewhere on the board
Tx_UART_6: MCU1.CN10_4 (PC6); also elsewhere on the board

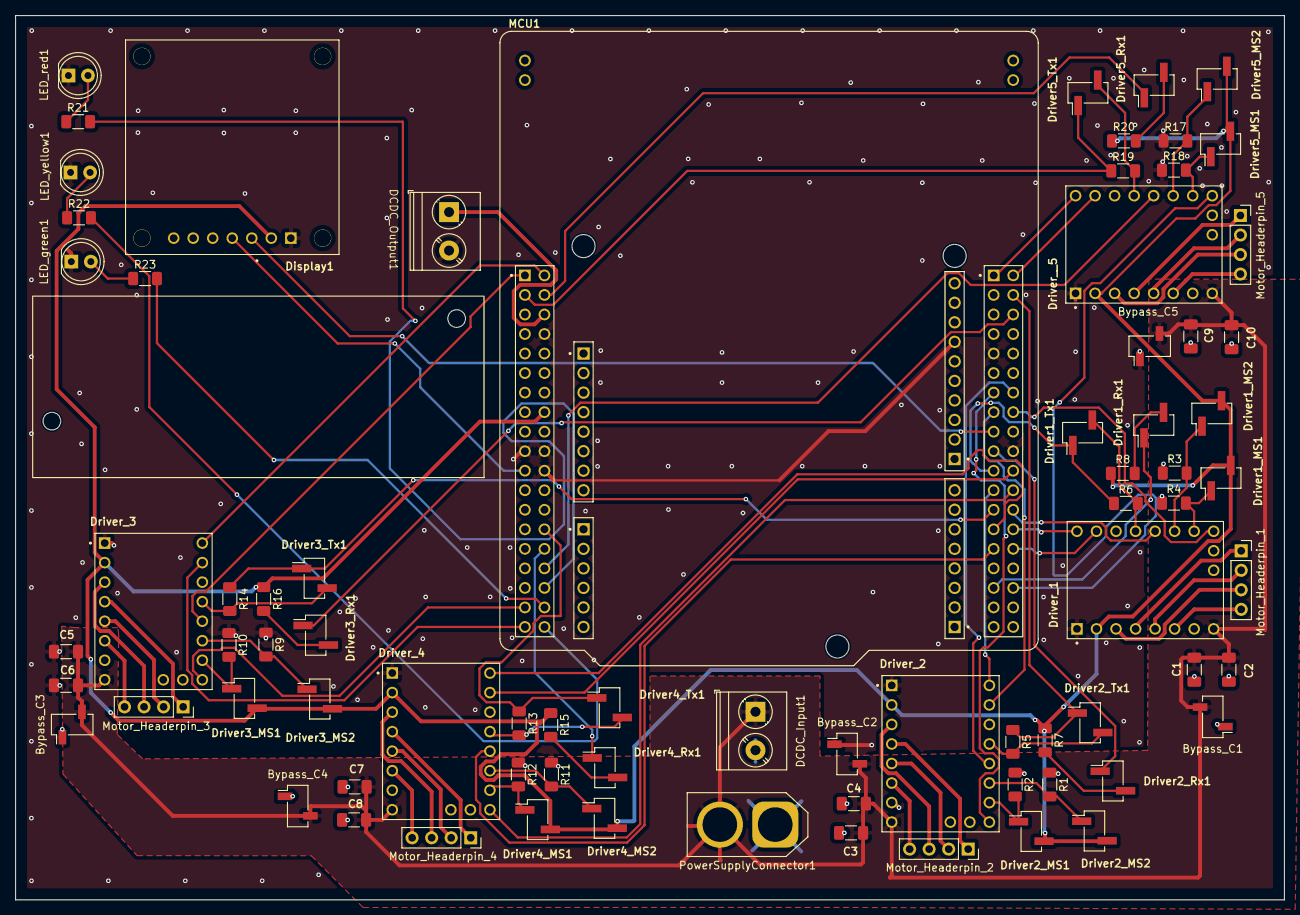
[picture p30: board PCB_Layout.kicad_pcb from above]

Board: 2 copper layers, 165.0 x 115.0 mm, 76 parts (0 on the bottom side), 82 nets.

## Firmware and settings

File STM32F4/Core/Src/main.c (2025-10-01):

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
/* Includes ------------------------------------------------------------------*/
#include "main.h"

/* USER CODE BEGIN Includes */
#include "motor/motor_init.h"
#include "motor/motor_types.h"
#include "motor/motor_control.h"
#include "motor/status_check.h"
/* USER CODE END Includes */

/* USER CODE BEGIN PD */

#define MOTOR_COUNT 5
/* USER CODE END PD */

I2C_HandleTypeDef hi2c1;

TIM_HandleTypeDef htim1;
TIM_HandleTypeDef htim3;
TIM_HandleTypeDef htim4;
TIM_HandleTypeDef htim6;
TIM_HandleTypeDef htim7;
TIM_HandleTypeDef htim8;
TIM_HandleTypeDef htim9;
TIM_HandleTypeDef htim10;
TIM_HandleTypeDef htim12;
TIM_HandleTypeDef htim13;

UART_HandleTypeDef huart4;
UART_HandleTypeDef huart5;
UART_HandleTypeDef huart1;
UART_HandleTypeDef huart2;
UART_HandleTypeDef huart3;
UART_HandleTypeDef huart6;

/* USER CODE BEGIN PV */
motor_t *motors[MOTOR_COUNT];
uint8_t start_flag;
/* USER CODE END PV */

void SystemClock_Config(void);
static void MX_GPIO_Init(void);
static void MX_USART2_UART_Init(void);
static void MX_USART1_UART_Init(void);
static void MX_I2C1_Init(void);
static void MX_UART4_Init(void);
static void MX_TIM3_Init(void);
static void MX_TIM4_Init(void);
static void MX_TIM9_Init(void);
static void MX_TIM8_Init(void);
static void MX_TIM12_Init(void);
static void MX_TIM13_Init(void);
static void MX_TIM1_Init(void);
static void MX_TIM6_Init(void);
static void MX_TIM7_Init(void);
static void MX_TIM10_Init(void);
static void MX_UART5_Init(void);
static void MX_USART3_UART_Init(void);
static void MX_USART6_UART_Init(void);
/* USER CODE BEGIN PFP */

#define PUTCHAR_PROTOTYPE int __io_putchar(int ch)
/* USER CODE END PFP */

/**
  * @brief  The application entry point.
  * @retval int
  */
int main(void)
{

  /* USER CODE BEGIN 1 */
	motor_t motor1;
	motor_t motor2;
	motor_t motor3;
	motor_t motor4;
	motor_t motor5;
	motors[0] = &motor1;
	motors[1] = &motor2;
	motors[2] = &motor3;
	motors[3] = &motor4;
	motors[4] = &motor5;

	tmc2209_stepper_driver_t driver1;
	tmc2209_stepper_driver_t driver2;
	tmc2209_stepper_driver_t driver3;
	tmc2209_stepper_driver_t driver4;
	tmc2209_stepper_driver_t driver5;

	motors[0]->driver = &driver1;
	motors[1]->driver = &driver2;
	motors[2]->driver = &driver3;
	motors[3]->driver = &driver4;
	motors[4]->driver = &driver5;

  /* USER CODE END 1 */

  /* MCU Configuration--------------------------------------------------------*/

  /* Reset of all peripherals, Initializes the Flash interface and the Systick. */
  HAL_Init();

  /* Configure the system clock */
  SystemClock_Config();

  /* Initialize all configured peripherals */
  MX_GPIO_Init();
  MX_USART2_UART_Init();
  MX_USART1_UART_Init();
  MX_I2C1_Init();
  MX_UART4_Init();
  MX_TIM3_Init();
  MX_TIM4_Init();
  MX_TIM9_Init();
  MX_TIM8_Init();
  MX_TIM12_Init();
  MX_TIM13_Init();
  MX_TIM1_Init();
  MX_TIM6_Init();
  MX_TIM7_Init();
  MX_TIM10_Init();
  MX_UART5_Init();
  MX_USART3_UART_Init();
  MX_USART6_UART_Init();
  /* USER CODE BEGIN 2 */
  initAllMotors(MODE_5_UART);

  while(start_flag == 0);


  goHome();

  moveToCoordinates(190, -70, 205, 90);
  moveToCoordinates(190, -70, 145, 90);

  grip();

  moveToCoordinates(190, -70, 205, 90);

  moveToCoordinates(165, 40, 205, 90);
  moveToCoordinates(165, 40, 95, 90);

  openGripper();

  moveToCoordinates(160, 30, 205, 90);

  moveToCoordinates(390, -70, 205, 90); // this coordinate not reachable


//  HAL_Delay(2000);
//////
//  moveToCoordinates(190, -70, 205, 90);
////  HAL_Delay(2000);
//////
//  moveToCoordinates(190, -70, 145, 90);
//  grip();
//  moveToCoordinates(190, -70, 205, 90);
//  HAL_Delay(2000);

//  moveDegrees(20, &motor2);
//
//  while(motor2.active_movement_flag)
//  {
//	  checkDriverStatus(&motor2);
//  }


  /* USER CODE END 2 */

  /* Infinite loop */
  /* USER CODE BEGIN WHILE */
  while (1)
  {
//	  checkAllDrivers();

    /* USER CODE END WHILE */

    /* USER CODE BEGIN 3 */
  }
  /* USER CODE END 3 */
}

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
/* USER CODE BEGIN 4 */


void HAL_GPIO_EXTI_Callback(uint16_t GPIO_Pin)
{
	if (GPIO_Pin == B1_Pin)  // Check if User Button
	{
		start_flag = 1;
	}
}

PUTCHAR_PROTOTYPE
{
  /* Place your implementation of fputc here */
  /* e.g. write a character to the USART1 and Loop until the end of transmission */
  HAL_UART_Transmit(&huart2, (uint8_t *)&ch, 1, 0xFFFF);

  return ch;
}
/* USER CODE END 4 */
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


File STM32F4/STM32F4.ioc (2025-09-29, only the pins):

Mcu.UserName=STM32F446RETx
PA0-WKUP.Signal=UART4_TX
PA1.Signal=UART4_RX
PA10.Signal=USART1_RX
PA11.Signal=GPIO_Input
PA13.GPIO_Label=TMS
PA13.Signal=SYS_JTMS-SWDIO
PA14.GPIO_Label=TCK
PA14.Signal=SYS_JTCK-SWCLK
PA2.GPIO_Label=USART_TX
PA2.Signal=USART2_TX
PA3.GPIO_Label=USART_RX
PA3.Signal=USART2_RX
PA4.Signal=GPIO_Input
PA5.GPIO_Label=LD2 [Green Led]
PA5.Signal=GPIO_Output
PA6.GPIO_Label=MOT_EN_2
PA6.Signal=GPIO_Output
PA7.GPIO_Label=STEP_2
PA7.Signal=GPIO_Output
PA8.GPIO_Label=DIR_2
PA8.Signal=GPIO_Output
PA9.Signal=USART1_TX
PB0.GPIO_Label=LED_red
PB0.Signal=GPIO_Output
PB1.GPIO_Label=MOT_EN_4
PB1.Signal=GPIO_Output
PB10.Signal=USART3_TX
PB12.GPIO_Label=MOT_EN_1
PB12.Signal=GPIO_Output
PB13.GPIO_Label=STEP_1
PB13.Signal=GPIO_Output
PB14.GPIO_Label=DIR_1
PB14.Signal=GPIO_Output
PB15.Signal=GPIO_Input
PB2.GPIO_Label=STEP_4
PB2.Signal=GPIO_Output
PB3.GPIO_Label=SWO
PB3.Signal=SYS_JTDO-SWO
PB4.GPIO_Label=DIR_4
PB4.Signal=GPIO_Output
PB5.Signal=GPIO_Input
PB6.Signal=I2C1_SCL
PB7.Signal=I2C1_SDA
PB9.GPIO_Label=DIAG_3
PB9.Signal=GPIO_Input
PC0.GPIO_Label=LED_yellow
PC0.Signal=GPIO_Output
PC1.GPIO_Label=LED_green
PC1.Signal=GPIO_Output
PC10.Signal=GPIO_Input
PC11.GPIO_Label=DIR_3
PC11.Signal=GPIO_Output
PC12.Signal=UART5_TX
PC13.GPIO_Label=B1 [Blue PushButton]
PC13.Signal=GPXTI13
PC14-OSC32_IN.Signal=RCC_OSC32_IN
PC15-OSC32_OUT.Signal=RCC_OSC32_OUT
PC2.GPIO_Label=MOT_EN_3
PC2.Signal=GPIO_Output
PC3.GPIO_Label=STEP_3
PC3.Signal=GPIO_Output
PC4.GPIO_Label=MOT_EN_5
PC4.Signal=GPIO_Output
PC5.Signal=USART3_RX
PC6.Signal=USART6_TX
PC7.Signal=USART6_RX
PC8.GPIO_Label=STEP_5
PC8.Signal=GPIO_Output
PC9.GPIO_Label=DIR_5
PC9.Signal=GPIO_Output
PD2.Signal=UART5_RX
PH0-OSC_IN.Signal=RCC_OSC_IN
PH1-OSC_OUT.Signal=RCC_OSC_OUT

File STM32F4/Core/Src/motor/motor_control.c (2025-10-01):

/*
 * motion.motor_control.c
 *  Created on: Jul 14, 2025
 *      Author: jakob
 */
#include "motor/motor_control.h"
#include "motor/status_check.h"
#include "math.h"
#include "display/helper.h"
#include "motor/motor_init.h"
#include "motor/helper.h"
#include "motor/kinematics.h"

//Globals
extern motor_t *motors[]; //To gain access to motor variables in interrupt service routine

#define NUMBER_OF_MOTOR 5


void initMovementVars(motor_t * motor, motion_mode_t motion_mode);
motor_error_t startMovement(motor_t * motor);
void stopMotorMovement(motor_t * motor);
static inline void trapezMove(motion_t * mt);
void HAL_TIM_OC_DelayElapsedCallback(TIM_HandleTypeDef* htim);
void HAL_TIM_PeriodElapsedCallback(TIM_HandleTypeDef* htim);
void HAL_GPIO_EXTI_Callback(uint16_t GPIO_Pin);
motor_error_t moveGripper(gripper_close_open_t direction);
void toggle_inverse_motor_direction(tmc2209_stepper_driver_t* stepper_driver);


void initMovementVars(motor_t * motor, motion_mode_t motion_mode)
{
	motor->motion.v = 0;
	motor->motion.step = 0;
	motor->motion.cycle = 0;
	motor->motion.motion_mode = motion_mode;
	motor->stallguard.stall_flag = 0;
}

/*
 * Starts the timer to start interrupts which are necessary for the motor movement.
 */
motor_error_t startMovement(motor_t * motor)
{
	HAL_StatusTypeDef status;
	motor_error_t error = NO_ERROR;

	HAL_GPIO_WritePin(motor->gpio_ports.step, motor->gpio_pins.step, GPIO_PIN_RESET);
	__HAL_TIM_SET_COMPARE(&motor->motion.motor_control_timer, TIM_CHANNEL_1, 1);
	status = HAL_TIM_OC_Start_IT(&motor->motion.motor_control_timer, TIM_CHANNEL_1);

	if (status != HAL_OK)
		error = MOTOR_ERROR;

	motor->active_movement_flag = 1;

	return error;
}

/*
 * Stops the motor movement by stopping the timer.
 */
void stopMotorMovement(motor_t * motor)
{
	HAL_TIM_OC_Stop_IT(&motor->motion.motor_control_timer, TIM_CHANNEL_1);
	motor->active_movement_flag = 0;
	initializeDefaults(motor);
}

/*
 * Trapezoidal motion profile (TrapezMove) – physical derivation
 *
 * The motion is divided into 3 phases:
 *   1) Acceleration: from v=0 to v_max with constant acceleration a_acc
 *   2) Constant velocity: v = v_max (if total distance is large enough)
 *   3) Deceleration: from v_max back to 0 with constant deceleration a_dec
 *
 * Fundamental kinematic relations:
 *   v = a * t
 *   s = 0.5 * a * t^2
 *   v^2 = 2 * a * s    (key equation for ramps)
 *
 * Acceleration phase:
 *   t_acc = v_max / a_acc
 *   s_acc = v_max^2 / (2 * a_acc)
 *
 * Deceleration phase:
 *   t_dec = v_max / a_dec
 *   s_dec = v_max^2 / (2 * a_dec)
 *
 * Constant velocity phase (if present. It won't be present if total distance isn't large enough):
 *   s_const = s_total - (s_acc + s_dec)
 *
 * If s_const >= 0 → trapezoidal profile (true trapez)
 * If s_const < 0  → triangular profile (no constant section)
 *
 * For the triangular profile:
 *   s_total = s_acc + s_dec
 *   s_acc = v_peak^2 / (2 * a_acc)
 *   s_dec = v_peak^2 / (2 * a_dec)
 *
 * Solve for v_peak:
 *   v_peak = sqrt( (2 * a_acc * a_dec) / (a_acc + a_dec) * s_total )
 *
 * Summary of implementation:
 *   - Precompute acc_steps, dec_steps, const_steps based on desired v_max, a_acc, a_dec.
 *   - If const_steps < 0, recalculate acc_steps, dec_steps using v_peak and set const_steps=0.
 *   - Online velocity update:
 *       Accel: v = sqrt(2 * a_acc * s)
 *       Const: v = v_max
 *       Decel: v = sqrt(2 * a_dec * s_remaining)
 */
static inline void trapezMove(motion_t* mt)
{
	if (mt->step >= 0 && mt->step < mt->acc_steps)
	{
		mt->v = sqrtf(2 * mt->ACC_MAX * (mt->step + 1));
		// motion.v = acc_ramp[motion.step]
	}
	else if (mt->const_steps != 0 && mt->step >= mt->acc_steps && mt->step < (mt->total_steps - mt->dec_steps))
		mt->v = mt->V_MAX;
	else if (mt->step >= (mt->total_steps - mt->dec_steps) && mt->step < mt->total_steps)
	{
		mt->v = sqrtf(2 * mt->DEC_MAX * (mt->total_steps - mt->step));
		// motion.v = acc_ramp[motion.total_steps - motion.step]
	}
}
/*
 *
 * Interrupt service routine for timer in output compare mode.
 * Timer counts until compare value is reached.
 * When value is reached, the GPIO toggles.
 * Every other motion.cycle, as motion.step only triggers on rising edge,
 * the velocity and the compare value is changed depending on current state of velocity ramp.
 *
 */
void HAL_TIM_OC_DelayElapsedCallback(TIM_HandleTypeDef *htim)
{
	int8_t index;
	motor_t* motor;

	//To know which timer and thus which motor caused the interrupt
	if (htim->Instance == motors[0]->motion.motor_control_timer.Instance){ index = 0; }
	else if (htim->Instance == motors[1]->motion.motor_control_timer.Instance){ index = 1; }
	else if (htim->Instance == motors[2]->motion.motor_control_timer.Instance){ index = 2; }
	else if (htim->Instance == motors[3]->motion.motor_control_timer.Instance){ index = 3; }
	else if (htim->Instance == motors[4]->motion.motor_control_timer.Instance){ index = 4; }

	motor = motors[index];
	motion_t* mt = &motor->motion;

	//Stop timer and movement if the robot reaches its destination
	if (mt->motion_mode == MOTION_TRAPEZ && mt->step >= mt->total_steps)
	{
		stopMotorMovement(motor);
		return;
	}

	if (mt->cycle % 2 == 0) //Change velocity only every other cycle because step only triggers on rising edge
	{
		switch(mt->motion_mode)
		{
		case MOTION_TRAPEZ:
			trapezMove(mt);
			break;
		case MOTION_HOME:	//Since we don't know the exact distance to move in these 2 following cases, there's no deceleration
		case MOTION_GRIP:
			if (mt->step >= 0 && mt->step < mt->acc_steps)
				mt->v = sqrtf(2 * mt->ACC_MAX * (mt->step + 1));
			else
				mt->v = mt->V_MAX;
			break;
		}
		mt->step++;
		//Track the position of motors in steps.
		if (mt->inverse_motor_direction)
			mt->position--;
		else
			mt->position++;

	}

	mt->cycle++;

	HAL_GPIO_TogglePin(motor->gpio_ports.step, motor->gpio_pins.step);

	/*
	 * 	To reach the desired speed, we need to calculate the delay between two toggles.
	 *	v is in µsteps/s or just 1/s because one µstep is one period.
	 *	For one period, the duration is 1/v.
	 *	Between two toggles, it is 1/(2*v).
	 *	But this is not the answer since the time has to be converted into timer ticks.
	 *	The timer runs at 2 MHz so we need to divide our current period duration by 1 / 2000000 s or 0.5 µs.
	 *	-> delay in ticks = 1/(2*v)/0.0000005 = 2000000/(2*v)
	 */

	int32_t delay = 2000000 / (2 * mt->v);
	//Add delay to current compare value in register
	int32_t total_delay = __HAL_TIM_GET_COMPARE(&mt->motor_control_timer, TIM_CHANNEL_1) + delay;
	__HAL_TIM_SET_COMPARE(&mt->motor_control_timer, TIM_CHANNEL_1, total_delay);
}
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

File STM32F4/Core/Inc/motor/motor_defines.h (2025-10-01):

/*
 * motor_defines.h
 *
 *  Created on: Aug 5, 2025
 *      Author: jakob
 */

#ifndef INC_MOTOR_DEFINES_H_
#define INC_MOTOR_DEFINES_H_

//Global defines
#define STEPS_PER_REV 200.0f
#define DEGREES_PER_REV 360.0f

//MOTOR 1 defines
#define GEAR_RATIO_M_1 10
#define MICROSTEPS_M_1 32

#define STEPS_PER_SEC_M_1 160
#define STEPS_PER_SEC2_M_1 125

#define V_MAX_M_1 (STEPS_PER_SEC_M_1 * MICROSTEPS_M_1)
#define ACC_MAX_M_1 (STEPS_PER_SEC2_M_1 * MICROSTEPS_M_1)
#define DEC_MAX_M_1 (STEPS_PER_SEC2_M_1 * MICROSTEPS_M_1)

#define HOLD_CURRENT_PERCENT_M_1 30
#define RUN_CURRENT_PERCENT_M_1 70

#define ANGLE_LIMIT_M_1 345.0f
#define POSITION_LIMIT_M_1 (((STEPS_PER_REV * (float)(MICROSTEPS_M_1) / DEGREES_PER_REV) * ANGLE_LIMIT_M_1) * GEAR_RATIO_M_1)
#define HIGH_LIMIT_M_1 353.57f
#define LOW_LIMIT_M_1 6.43f

#define LOW_COUNTER_THRESHOLD_M_1 1
#define STALL_MAX_M_1 168.0f
#define STALL_BUFFER_M_1 25

//MOTOR 2 defines
#define GEAR_RATIO_M_2 7.5
#define MICROSTEPS_M_2 32

#define STEPS_PER_SEC_M_2 100
#define STEPS_PER_SEC2_M_2 80

#define V_MAX_M_2 (STEPS_PER_SEC_M_2 * MICROSTEPS_M_2)
#define ACC_MAX_M_2 (STEPS_PER_SEC2_M_2 * MICROSTEPS_M_2)
#define DEC_MAX_M_2 (STEPS_PER_SEC2_M_2 * MICROSTEPS_M_2)

#define HOLD_CURRENT_PERCENT_M_2 90
#define RUN_CURRENT_PERCENT_M_2 100

#define ANGLE_LIMIT_M_2 116.0f
#define POSITION_LIMIT_M_2 (((STEPS_PER_REV * (float)(MICROSTEPS_M_2) / DEGREES_PER_REV) * ANGLE_LIMIT_M_2) * GEAR_RATIO_M_2)
#define HIGH_LIMIT_M_2 116.92f
#define LOW_LIMIT_M_2 0.0f

#define LOW_COUNTER_THRESHOLD_M_2 1
#define STALL_MAX_M_2 82.4f
#define STALL_BUFFER_M_2 40

//MOTOR 3 defines
#define GEAR_RATIO_M_3 7.5
#define MICROSTEPS_M_3 32

#define STEPS_PER_SEC_M_3 150
#define STEPS_PER_SEC2_M_3 200

#define V_MAX_M_3 (STEPS_PER_SEC_M_3 * MICROSTEPS_M_3)
#define ACC_MAX_M_3 (STEPS_PER_SEC2_M_3 * MICROSTEPS_M_3)
#define DEC_MAX_M_3 (STEPS_PER_SEC2_M_3 * MICROSTEPS_M_3)

#define HOLD_CURRENT_PERCENT_M_3 40
#define RUN_CURRENT_PERCENT_M_3 60

#define ANGLE_LIMIT_M_3 116.0f
#define POSITION_LIMIT_M_3 (((STEPS_PER_REV * (float)(MICROSTEPS_M_3) / DEGREES_PER_REV) * ANGLE_LIMIT_M_3) * GEAR_RATIO_M_3)
#define HIGH_LIMIT_M_3 138.77f
#define LOW_LIMIT_M_3 0.0f

#define LOW_COUNTER_THRESHOLD_M_3 1
#define STALL_MAX_M_3 140.0f
#define STALL_BUFFER_M_3 25

//MOTOR 4 defines
#define GEAR_RATIO_M_4 7.5
#define MICROSTEPS_M_4 8

#define STEPS_PER_SEC_M_4 200
#define STEPS_PER_SEC2_M_4 150

#define V_MAX_M_4 (STEPS_PER_SEC_M_4 * MICROSTEPS_M_4)
#define ACC_MAX_M_4 (STEPS_PER_SEC2_M_4 * MICROSTEPS_M_4)
#define DEC_MAX_M_4 (STEPS_PER_SEC2_M_4 * MICROSTEPS_M_4)

#define HOLD_CURRENT_PERCENT_M_4 50
#define RUN_CURRENT_PERCENT_M_4 70

#define ANGLE_LIMIT_M_4 180.0f
#define POSITION_LIMIT_M_4 (((STEPS_PER_REV * (float)(MICROSTEPS_M_4) / DEGREES_PER_REV) * ANGLE_LIMIT_M_4) * GEAR_RATIO_M_4)
#define HIGH_LIMIT_M_4 180
#define LOW_LIMIT_M_4 0

#define LOW_COUNTER_THRESHOLD_M_4 1
#define STALL_MAX_M_4 39.0f
#define STALL_BUFFER_M_4 7

//MOTOR 5 defines
#define GEAR_RATIO_M_5 1
#define MICROSTEPS_M_5 1

#define STEPS_PER_SEC_M_5 1000
#define STEPS_PER_SEC2_M_5 800

#define V_MAX_M_5 (STEPS_PER_SEC_M_5 * MICROSTEPS_M_5)
#define ACC_MAX_M_5 (STEPS_PER_SEC2_M_5 * MICROSTEPS_M_5)
#define DEC_MAX_M_5 (STEPS_PER_SEC2_M_5 * MICROSTEPS_M_5)

#define HOLD_CURRENT_PERCENT_M_5 20
#define RUN_CURRENT_PERCENT_M_5 20

#define GRIPPER_POS_LIMIT 160000
#define POSITION_LIMIT_M_5 (GRIPPER_POS_LIMIT * GEAR_RATIO_M_5)

#define LOW_COUNTER_THRESHOLD_M_5 1
#define STALL_MAX_M_5 190.0f
#define STALL_BUFFER_M_5 25
#define STALL_GRIP_BUFFER_M_5 37

#endif /* INC_MOTOR_DEFINES_H_ */

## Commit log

2025-08-14 two motors at the same time working
2025-08-19 5 Motors working. Currently working on StallGuard implementation.
    [STM32F4.ioc, main.c, motor_control.c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]
2025-08-29 stallguard implemented and working reliable, now working on fine tuning
    [STM32F4.ioc, main.c, motor_control.c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]
2025-08-29 Sensorless Homing with stallGuard now works
    [main.c, motor_control.c, motor_defines.h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]
2025-09-12 remove update V_MAX, modify openGripper while Homing
2025-09-16 organization of files and updated kinematics
2025-09-23 Added Creo8 CAD assembly and parts
2025-09-23 added option to use 2 UARTs instead of 5
2025-09-29 STL files and STEP Model added
    [abdeckung_oben.stl, abdeckung_vorne.stl, distanz_nema17_e1.stl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]
2025-09-29 two UART Mode implemented and tested
2025-09-30 added instructions and order list to build roboter
    [Bestellliste.xlsx]
2025-09-30 updated order list
    [Bestellliste.xlsx]
2025-09-30 Readme updated
    [abdeckung_oben.stl, abdeckung_vorne.stl, distanz_nema17_e1.stl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]
2025-09-30 Added Elektronik
    [AOM12864A0-1.54WW-ANO.step, DM-OLED096-636.step, PCB_Layout.kicad_pcb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]
2025-09-30 Added Screws, washers, nuts
2025-10-01 Added Assembly description
2025-10-01 added LEDs green and yellow, modified Stall_Buffer_5
    [main.c, motor_control.c, motor_defines.h]

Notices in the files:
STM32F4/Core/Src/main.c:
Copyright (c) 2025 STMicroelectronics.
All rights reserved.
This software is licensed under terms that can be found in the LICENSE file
